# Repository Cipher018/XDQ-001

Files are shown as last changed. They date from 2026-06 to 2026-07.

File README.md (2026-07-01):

# XDQ-001

## Introduction

## What is XDQ-001?

The **XDQ-001**, or **Experimental Drone Quadcopter Model 001**, is a flight platform with an original design. Its experimental objective is to achieve a FPV quadcopter capable of both acrobatic flight and cinematic filming. Furthermore, the XDQ-001 platform serves as a cutting-edge testbed for implementing highly optimized low-level control and autonomous navigation algorithms.

## Whats New?

The **XDQ-001** represents a massive generational leap over its predecessor (XDF-001), integrating the following hardware and firmware innovations (Version V001):

1. **Hybrid Cooperative Interrupt-Based Architecture (No RTOS):**
   - **1000Hz Critical Loop:** Hardware Timer ISR dedicated exclusively to attitude (AHRS), PID calculations, and motor control.
   - **50Hz Kinematic Loop:** Background loop for Kalman filtering, waypoint navigation, and geometric estimation.
2. **Dual-Layer Navigation System:**
   - **Layer 1 (Attitude):** Optimized Mahony AHRS filter running at 1000Hz.
   - **Layer 2 (Kinematics):** Three-Dimensional Error State Kalman Filter (3D ESKF) at 50Hz, fusing accelerometer, GPS, and barometer (BMP280) measurements.
3. **CADI_A Adaptive Navigation System:**
   - Advanced algorithms for L1 navigation (adaptive waypoints) and Orbit (loiter).
   - **Stochastic Wind Estimator (Pitot-less):** Calculates and compensates for crosswind in real-time without requiring a pitot tube, based on geometric discrepancy during turns.
4. **Advanced Flight Control (FlightPID):** Isolated bandwidth PIDs (LPF_PT1 filters on P and D terms).
5. **Dynamic Safety Guards:**
   - *Dynamic Stall Guard:* Dynamic stall prevention based on bank angle.
   - *G-Limiter:* Pilot control limitation when the safe structural G-load (2.0G - 3.5G) is exceeded.
   - *Failsafe RTL:* Safe automatic Return-To-Launch on link loss.
6. **Dedicated Hardware:** MCU STM32F4 (with FPU), dedicated ICM-42688 IMU, MMC5983MA external magnetometer, and SX1280 long-range modem.
7. **Secure Communications & Telemetry:** Frequency Hopping Spread Spectrum (FHSS), logical dual-pipe, and strong cross-block encryption (XXTEA) with integrated CRC16.
8. **Uninterrupted Blackbox Logging:** Lock-free Ping-Pong buffers linked via DMA to the W25Q32JVSS Flash memory.

## Objectives

The primary objective is to develop an exceptional FPV quadcopter capable of both extreme acrobatic flight and smooth cinematic tracking.

The secondary objectives are:
- Provide an ultra-fast, predictable, non-RTOS software framework.
- Consolidate the capabilities of the CADI autonomous ecosystem (Waypoints, Orbits, auto RTL).
- Implement and refine stochastic estimation systems (ESKF and Wind Estimator).
- Establish an impenetrable telemetry system (robust encryption and FHSS).

## Architecture

As previously mentioned, the project is based on the STM32F4 architecture utilizing a hybrid cooperative interrupt-based system. You can consult the documentation section for details regarding the PCB, algorithms, or flowcharts.

## Hardware

The XDQ-001 uses a custom Flight Control Board (FCB) built around the **STM32F4** microcontroller. Key sensors and components:

- **IMU (Gyro/Accel):** ICM‑42688‑P
- **Magnetometer:** MMC5983MA
- **Barometer:** BMP280
- **Radio Link:** SX‑1280 (FHSS Support)
- **Storage:** W25Q32JVSS Flash Memory
- **Camera:** Caddx Baby Ratel 2 (optional)

A full Bill of Materials (BOM) is still being defined.

## Software

- Development is currently performed using the **Arduino IDE** (with the STM32 core) but migration to a more advanced toolchain is planned.
- No ground control station (GCS) software exists yet; a future GCS will communicate via the SX‑1280 radio.

## Compilation & Installation

The firmware follows the standard Arduino IDE project layout:

1. Open the `Firmware/` folder and load `XDQ-001F_V001.ino`.
2. Select the appropriate **STM32F4** board definition.
3. Ensure FPU support is enabled if required.
4. Verify / compile the sketch (`Ctrl+R`) and upload using a compatible programmer (e.g., ST-Link V2) or USB DFU bootloader.

## Usage

1. Power the FCB and connect the radio module.
2. Power the drone and perform a basic motor test (ensure propellers are removed).
3. When the GCS becomes available, pair it with the SX‑1280 radio and start telemetry.

## Configuration

At present the firmware has no runtime‑configurable parameters. Future releases will expose PID and filter tuning via the GCS.

## Contributing

Contributions are welcome under an **MIT license**. Please:

- Fork the repository and create a feature branch.
- Follow the existing code style (Arduino‑C++ with descriptive comments).
- Ensure any additions maintain the non-blocking philosophy of the 1000Hz critical loop.
- Open a Pull Request with a clear description of changes.

## License

This project is licensed under the **MIT License**. See the `LICENSE` file for details.

## Documentation

It is highly recommended to review the comprehensive documentation to understand the mathematical and algorithmic details:

- 📄 **[Firmware Reference Manual (Markdown)](Documentation/firmware_reference.md)**
- 📕 **[Firmware Reference Manual (PDF)](Documentation/firmware_reference.pdf)**
- 📐 [Architecture Diagram](Documentation/architecture.md) (Pending migration)
- 🔌 [Pinout & Hardware](Documentation/pinout.md) (Pending migration)
- 📡 [Protocols](Documentation/protocol.md) (Pending migration)

## Project Structure

The repository is organized as follows:

- **Firmware/** – Arduino sketch source files (`*.ino`, drivers, control algorithms, telemetry).
- **Documentation/** – Design documents, architecture diagrams, pin‑out tables, protocol specifications, and other reference material.
- **CAD/** – 3D models and mechanical drawings for printable parts.
- **PCB/** – PCB design files, gerbers, and component placement.
- **References/** – Datasheets, application notes, and external resources used during development.
- **README.md** – This high‑level overview.
- **LICENSE** – MIT license file.

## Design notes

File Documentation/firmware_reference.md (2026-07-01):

# Firmware Reference Manual - XDQ-001
**Document Version:** 1.0  
**Firmware Version:** V001  
**Platform:** STM32F4 (with FPU)  

---

## Table of Contents
1. [System Architecture](#1-system-architecture)
2. [Dual-Layer Navigation System](#2-dual-layer-navigation-system)
3. [Flight Control & Safety](#3-flight-control--safety)
4. [Adaptive Navigation & Wind Estimation](#4-adaptive-navigation--wind-estimation)
5. [Secure Communications & Telemetry](#5-secure-communications--telemetry)
6. [Blackbox Logging](#6-blackbox-logging)

---

## 1. System Architecture

The XDQ-001 firmware implements a hybrid cooperative interrupt-based architecture (without RTOS) designed to optimize CPU cycles and guarantee strict timings in critical loops.

*   **Critical Attitude Loop (1000Hz):** Executed via a Hardware Timer Interrupt (`Timer_ISR`). This loop handles IMU reading, the AHRS filter, PID calculations, and PWM mixer updates for the motors.
*   **Kinematic and Cooperative Loop (50Hz):** Executed in the main block (`loop`). It handles less time-critical tasks such as reading the GPS, Magnetometer, and Barometer, executing the Kalman Filter, and waypoint navigation.

---

## 2. Dual-Layer Navigation System

One of the main technological innovations of the XDQ-001 is its dual approach to estimating attitude and kinematics.

### 2.1. Layer 1: Mahony AHRS Filter (Attitude)
For high-frequency orientation estimation, the firmware utilizes an optimized **Mahony AHRS** filter, processed in the 1000Hz loop.
*   Integrates raw high-speed readings from the ICM-42688 (Gyroscope and Accelerometer).
*   Maintains short-term stability and calculates quaternions that are converted to Euler angles (Roll, Pitch, Yaw), which are essential for acrobatic flight PIDs.

### 2.2. Layer 2: 3D Error State Kalman Filter (Kinematics)
For autonomous navigation, an Error State Kalman Filter (ESKF) processed at 50Hz fuses data from multiple sensors:
*   **System Model:** Maintains the state vector for 3D position and 3D velocity (N/E/D Position, N/E/D Velocity).
*   **Prediction:** Integrates accelerations transformed to the Earth's geographic frame using the AHRS quaternions.
*   **Update:** Uses latitude, longitude, altitude (fused with Barometer), and velocities provided by the GPS.

---

## 3. Flight Control & Safety

Stabilized control is achieved through an isolated controller class (`FlightPID`), complemented by dynamic aerodynamic safeguards.

### 3.1. Isolated Bandwidth PIDs
The PID loops implement PT1 low-pass filters (`LPF_PT1`) on the Proportional and Derivative terms, allowing more aggressive gains while rejecting electrical noise and mechanical vibrations induced by the frame.

### 3.2. Dynamic Safeguards
*   **Dynamic Stall Guard:** Continuously adjusts the stall speed threshold based on the bank angle. If the aircraft's speed drops below the safe threshold, the system autonomously injects negative pitch (nose down) and raises the throttle.
*   **G-Limiter:** Monitors the total G-load measured by the accelerometers and progressively attenuates pilot setpoints when detecting between 2.0 and 3.5 Gs to protect the structural frame.

---

## 4. Adaptive Navigation & Wind Estimation

The firmware introduces advanced autonomous capabilities from the CADI_A ecosystem.

### 4.1. Stochastic Wind Estimator (Pitot-less)
The XDQ-001 calculates the 2D wind vector by comparing the ground velocity vector (from GPS) with the directional attitude vector (nose direction). By applying a low-pass filter and utilizing averages during turns, the drone can determine wind direction and speed without additional hardware.

### 4.2. Guidance Algorithms (L1 & Orbit)
*   **Adaptive L1 Navigation:** Uses a lateral acceleration (L1) algorithm to smoothly generate roll corrections towards the next waypoint, integrating the crosswind compensation calculated by the wind estimator.
*   **TECS Control (Energy):** Employs a simplified variant of the Total Energy Control System (TECS), managing pitch (potential energy) and throttle (kinetic energy) simultaneously.
*   **Orbit:** Maintains a circular turn radius around a defined point by continuously controlling the radial error.

---

## 5. Secure Communications & Telemetry

The drone communicates using an SX1280 modem.
*   **Dual-Pipe:** Logically separates control/command packets (`0xAA`) and waypoint configuration packets (`0xAC`).
*   **Spread Spectrum (FHSS):** Automatic high-speed frequency hopping across 8 channels to evade interference.
*   **Cryptography:** All telemetry and commands use strong **XXTEA** cross-block encryption coupled with a CRC-16 checksum for authenticity and integrity.

---

## 6. Blackbox Logging

*   **Ping-Pong DMA Access:** Uses lock-free double buffers to write 32-byte logs to the W25Q32JVSS Flash memory. This ensures that data capture (attitude, vibration, motor states) does not halt the 1000Hz loop under any circumstances.

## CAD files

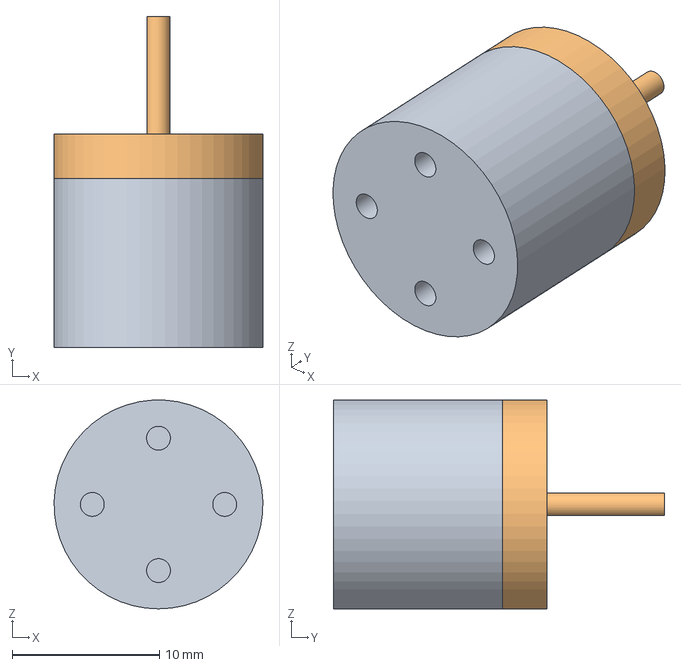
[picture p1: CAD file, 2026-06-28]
CAD/Motor.step
14.2 x 22.5 x 14.2 mm

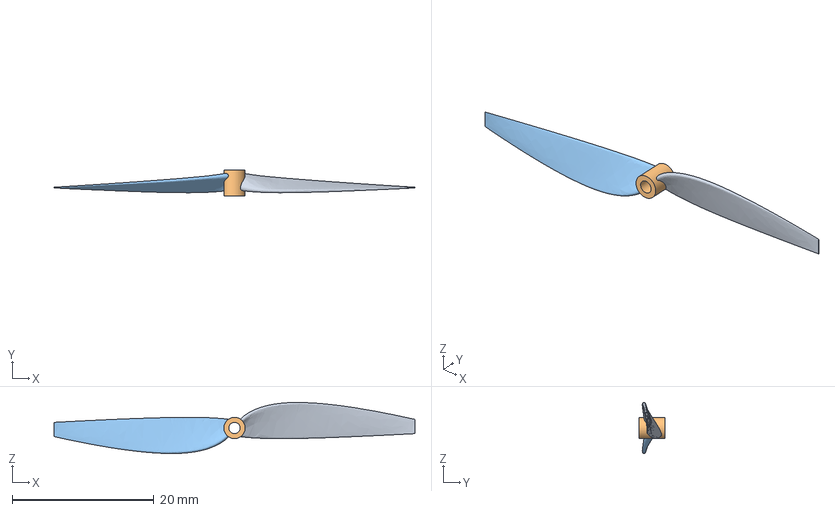
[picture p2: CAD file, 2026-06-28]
CAD/Helice.step
50.9 x 3.70 x 7.20 mm

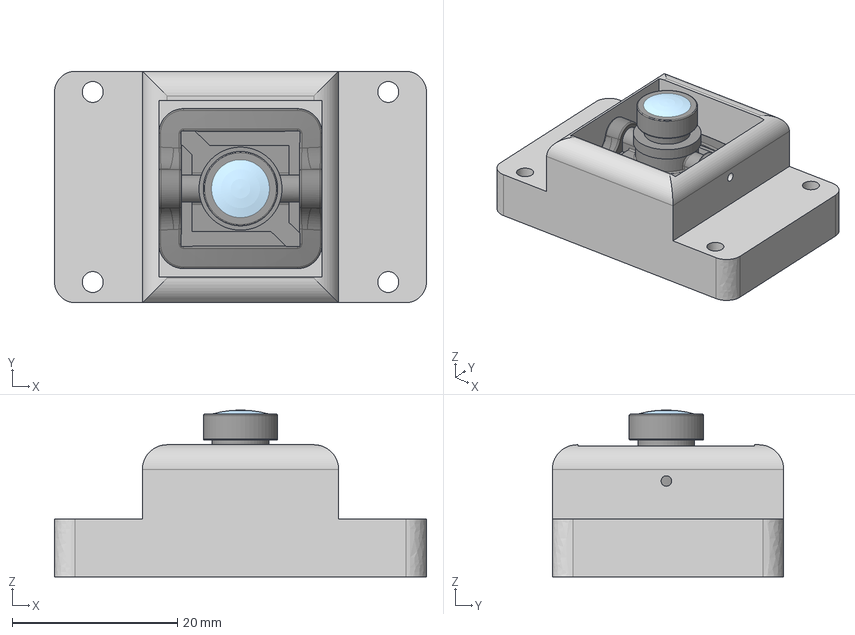
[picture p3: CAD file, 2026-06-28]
CAD/Montura + Camara.step
45.0 x 28.0 x 20.2 mm
CADDX BABY RATEL 2 PROTECTOR
CADDX BABY RATEL 2 CAMERA

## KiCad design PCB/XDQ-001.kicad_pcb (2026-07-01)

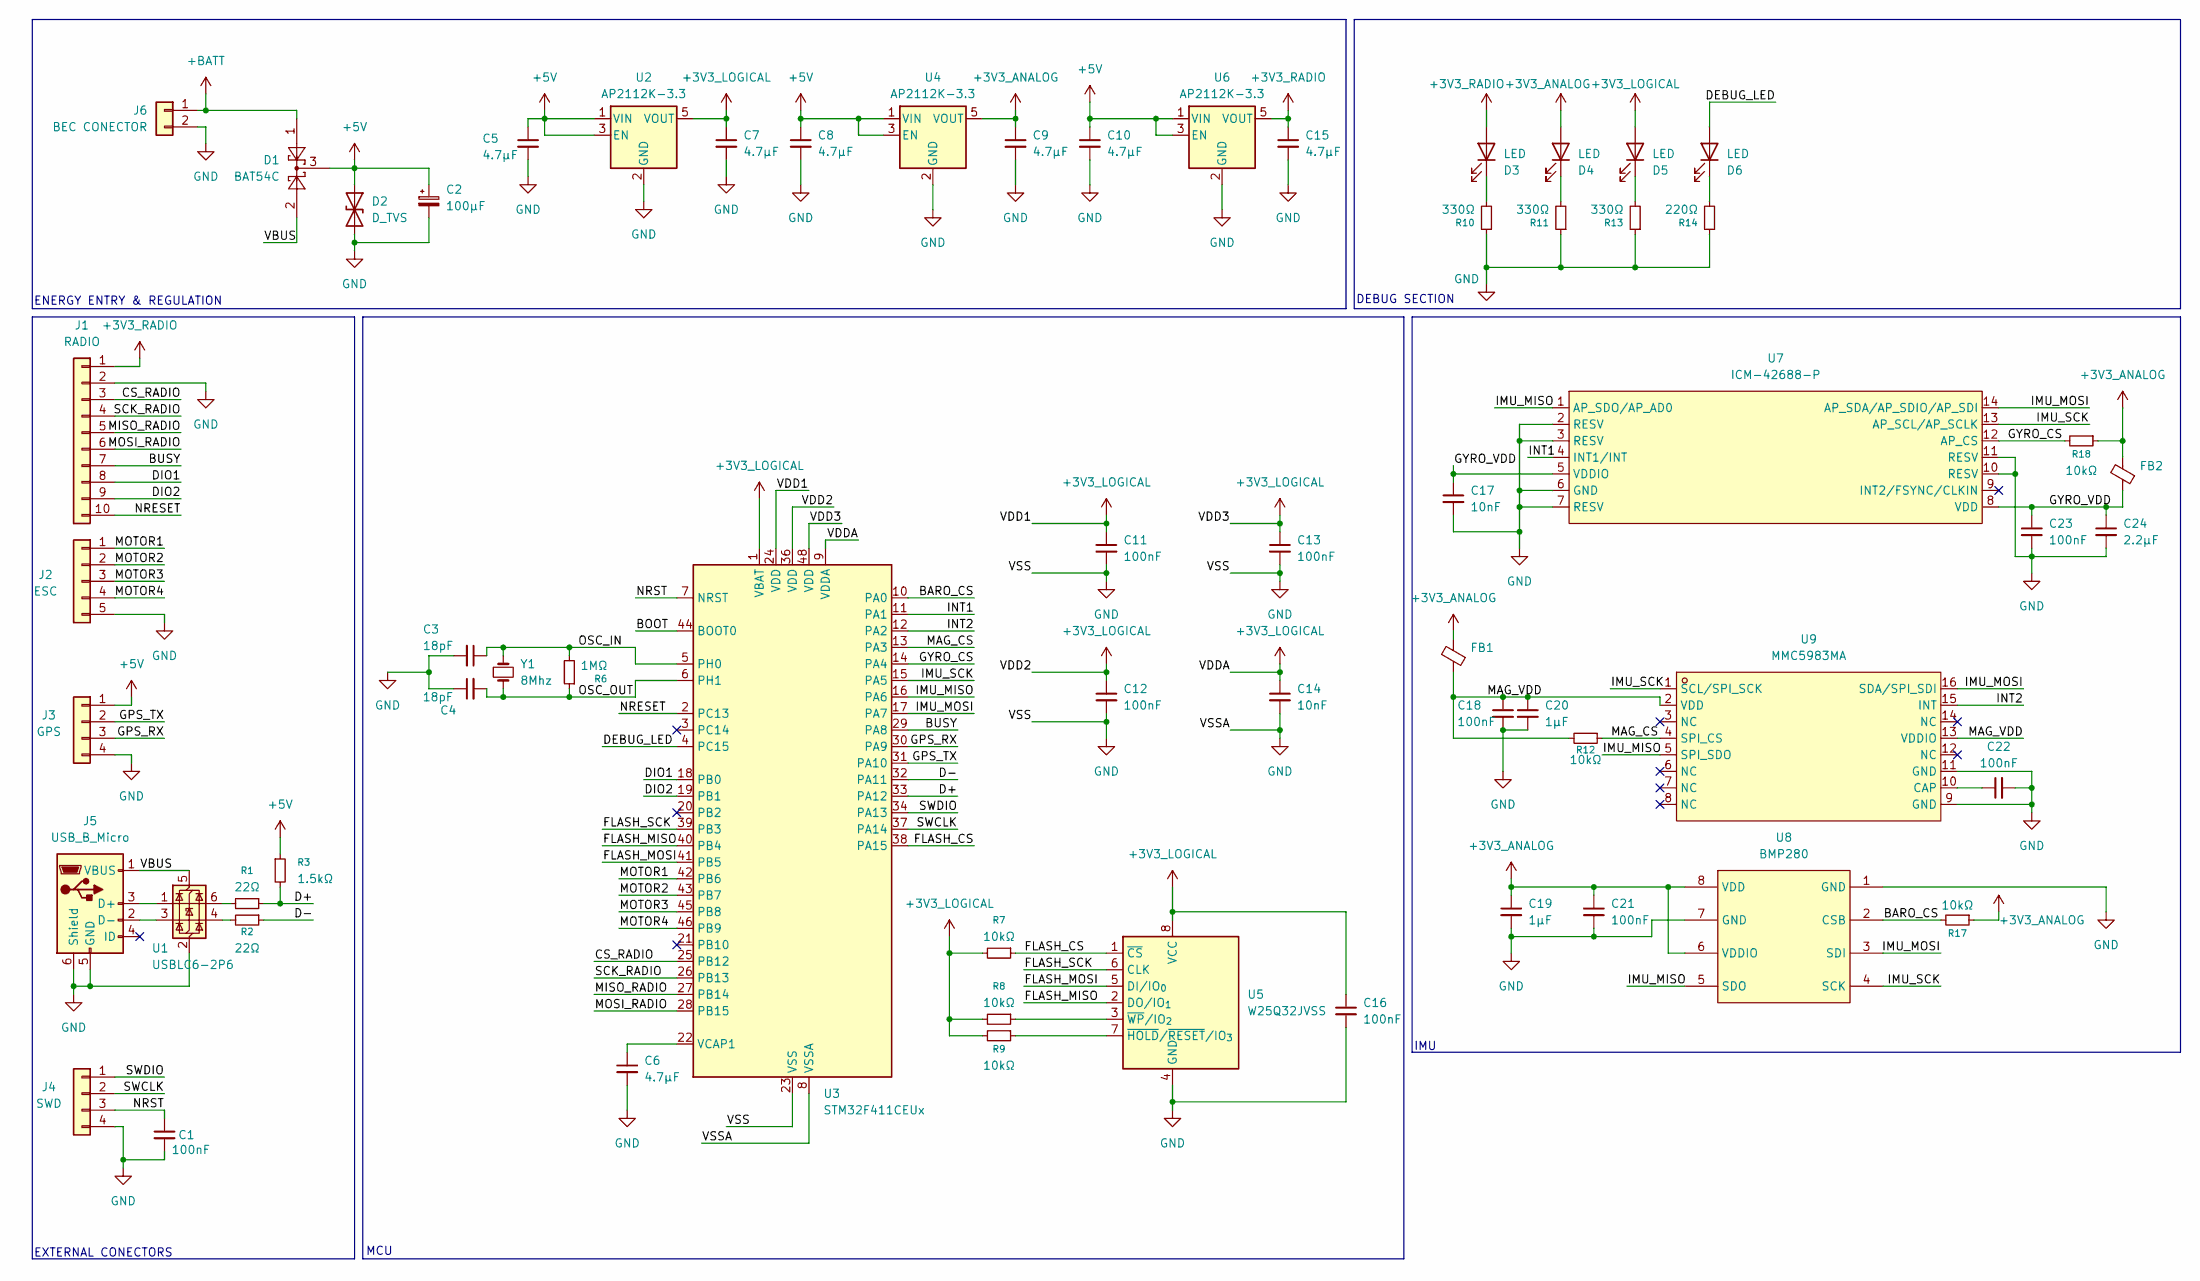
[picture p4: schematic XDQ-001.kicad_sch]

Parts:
C1, C11, C12, C13, C16, C18, C21, C22, C23: 100nF; C_0402_1005Metric_Pad0.74x0.62mm_HandSolder
C2: 100µF; CP_Elec_5x5.3
C3, C4: 18pF; C_0402_1005Metric_Pad0.74x0.62mm_HandSolder
C5, C6, C7, C8, C9, C10, C15: 4.7µF; C_0603_1608Metric_Pad1.08x0.95mm_HandSolder
C14, C17: 10nF; C_0402_1005Metric_Pad0.74x0.62mm_HandSolder
C19, C20: 1µF; C_0603_1608Metric_Pad1.08x0.95mm_HandSolder
C24: 2.2µF; C_0402_1005Metric_Pad0.74x0.62mm_HandSolder
D1: BAT54C; SOT-23
D2: D_TVS; D_SMB
D3, D4, D5, D6: LED; LED_0603_1608Metric_Pad1.05x0.95mm_HandSolder
FB1, FB2: FerriteBead_Small; L_0402_1005Metric
J1: RADIO; SolderWirePad_1x10_SMD_1.5x3mm
J2: ESC; SolderWirePad_1x05_SMD_1.5x3mm
J3: GPS; JST_PH_B4B-PH-K_1x04_P2.00mm_Vertical
J4: SWD; JST_PH_B4B-PH-K_1x04_P2.00mm_Vertical
J5: USB_B_Micro; USB_Micro-B_GCT_USB3076-30-A
J6: BEC CONECTOR; JST_PH_B2B-PH-K_1x02_P2.00mm_Vertical
R1, R2: 22Ω; R_0402_1005Metric_Pad0.72x0.64mm_HandSolder
R3: 1.5kΩ; R_0402_1005Metric_Pad0.72x0.64mm_HandSolder
R6: 1MΩ; R_0402_1005Metric_Pad0.72x0.64mm_HandSolder
R7, R8, R9, R12, R17, R18: 10kΩ; R_0402_1005Metric_Pad0.72x0.64mm_HandSolder
R10, R11, R13: 330Ω; R_0402_1005Metric_Pad0.72x0.64mm_HandSolder
R14: 220Ω; R_0402_1005Metric_Pad0.72x0.64mm_HandSolder
U1: USBLC6-2P6; SOT-666
U2, U4, U6: AP2112K-3.3; SOT-23-5
U3: STM32F411CEUx; QFN-48-1EP_7x7mm_P0.5mm_EP5.6x5.6mm
U5: W25Q32JVSS; SOIC-8_5.3x5.3mm_P1.27mm
U7: ICM-42688-P; LGA-14_L3.0-W2.5-P0.50-TL; MPN ICM-42688-P; LCSC Part C1850418
U8: BMP280; LGA-8_L2.5-W2.0-P0.65_AMP6127; MPN BMP280; LCSC Part C83291
U9: MMC5983MA; LGA-16_L3.0-W3.0-P0.50-BL_SQ; MPN MMC5983MA; LCSC Part C404329
Y1: 8Mhz; Crystal_SMD_2012-2Pin_2.0x1.2mm_HandSoldering

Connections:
+3V3_ANALOG: C9.1, C19.1, C21.1, D4.2 (A), FB1.2, FB2.2, R17.1, R18.1, U4.5 (VOUT), U8.6 (VDDIO), U8.8 (VDD)
+3V3_LOGICAL: C7.1, C11.1, C12.1, C13.1, C14.1, C16.1, D5.2 (A), R7.2, R8.2, R9.2, U2.5 (VOUT), U3.1 (VBAT), U3.9 (VDDA), U3.24 (VDD), U3.36 (VDD), U3.48 (VDD), U5.8 (VCC)
+3V3_RADIO: C15.1, D3.2 (A), J1.1, U6.5 (VOUT)
+5V: C2.1, C5.1, C8.1, C10.1, D1.3, D2.1 (A1), J3.1, R3.1, U2.1 (VIN), U2.3 (EN), U4.1 (VIN), U4.3 (EN), U6.1 (VIN), U6.3 (EN)
+BATT: D1.1, J6.1
/BARO_CS: R17.2, U3.10 (PA0), U8.2 (CSB)
/BOOT: U3.44 (BOOT0)
/BUSY: J1.7, U3.29 (PA8)
/CS_RADIO: J1.3, U3.25 (PB12)
/D+: R1.1, R3.2, U3.33 (PA12)
/D-: R2.1, U3.32 (PA11)
/DEBUG_LED: D6.2 (A), U3.4 (PC15)
/DIO1: J1.8, U3.18 (PB0)
/DIO2: J1.9, U3.19 (PB1)
/FLASH_CS: R7.1, U3.38 (PA15), U5.1 (~CS)
/FLASH_MISO: U3.40 (PB4), U5.2 (DO/IO_{1})
/FLASH_MOSI: U3.41 (PB5), U5.5 (DI/IO_{0})
/FLASH_SCK: U3.39 (PB3), U5.6 (CLK)
/GPS_RX: J3.3, U3.30 (PA9)
/GPS_TX: J3.2, U3.31 (PA10)
/GYRO_CS: R18.2, U3.14 (PA4), U7.12 (AP_CS)
/GYRO_VDD: C17.1, C23.1, C24.1, FB2.1, U7.5 (VDDIO), U7.8 (VDD)
/IMU_MISO: U3.16 (PA6), U7.1 (AP_SDO/AP_AD0), U8.5 (SDO), U9.5 (SPI_SDO)
/IMU_MOSI: U3.17 (PA7), U7.14 (AP_SDA/AP_SDIO/AP_SDI), U8.3 (SDI), U9.16 (SDA/SPI_SDI)
/IMU_SCK: U3.15 (PA5), U7.13 (AP_SCL/AP_SCLK), U8.4 (SCK), U9.1 (SCL/SPI_SCK)
/INT1: U3.11 (PA1), U7.4 (INT1/INT)
/INT2: U3.12 (PA2), U9.15 (INT)
/MAG_CS: R12.1, U3.13 (PA3), U9.4 (SPI_CS)
/MAG_VDD: C18.1, C20.1, FB1.1, R12.2, U9.2 (VDD), U9.13 (VDDIO)
/MISO_RADIO: J1.5, U3.27 (PB14)
/MOSI_RADIO: J1.6, U3.28 (PB15)
/MOTOR1: J2.1, U3.42 (PB6)
/MOTOR2: J2.2, U3.43 (PB7)
/MOTOR3: J2.3, U3.45 (PB8)
/MOTOR4: J2.4, U3.46 (PB9)
/NRESET: J1.10, U3.2 (PC13)
/NRST: C1.1, J4.3, U3.7 (NRST)
/OSC_IN: C3.1, R6.2, U3.5 (PH0), Y1.1
/OSC_OUT: C4.2, R6.1, U3.6 (PH1), Y1.2
/SCK_RADIO: J1.4, U3.26 (PB13)
/SWCLK: J4.2, U3.37 (PA14)
/SWDIO: J4.1, U3.34 (PA13)
/VBUS: D1.2, J5.1 (VBUS), U1.5 (VBUS)
GND: C1.2, C2.2, C3.2, C4.1, C5.2, C6.2, C7.2, C8.2, C9.2, C10.2, C11.2, C12.2, C13.2, C14.2, C15.2, C16.2, C17.2, C18.2, C19.2, C20.2, C21.2, C22.2, C23.2, C24.2, D2.2 (A2), J1.2, J2.5, J3.4, J4.4, J5.5 (GND), J5.6 (Shield), J6.2, R10.1, R11.1, R13.1, R14.1, U1.2 (GND), U2.2 (GND), U3.8 (VSSA), U3.23 (VSS), U3.35 (VSS), U3.47 (VSS), U3.49 (VSS), U4.2 (GND), U5.4 (GND), U6.2 (GND), U7.2 (RESV), U7.3 (RESV), U7.6 (GND), U7.7 (RESV), U7.10 (RESV), U7.11 (RESV), U8.1 (GND), U8.7 (GND), U9.9 (GND), U9.11 (GND)
unnamed: D3.1 (K), R10.2
unnamed: D4.1 (K), R11.2
unnamed: D5.1 (K), R13.2
unnamed: D6.1 (K), R14.2
unnamed: J5.3 (D+), U1.1 (I/O1)
unnamed: J5.2 (D-), U1.3 (I/O2)
unnamed: R1.2, U1.6 (I/O1)
unnamed: R2.2, U1.4 (I/O2)
unnamed: C6.1, U3.22 (VCAP1)
unnamed: R9.1, U5.7 (~HOLD/~RESET/IO_{3})
unnamed: R8.1, U5.3 (~WP/IO_{2})
unnamed: C22.1, U9.10 (CAP)

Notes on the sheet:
EXTERNAL CONECTORS
DEBUG SECTION
IMU
MCU
ENERGY ENTRY & REGULATION

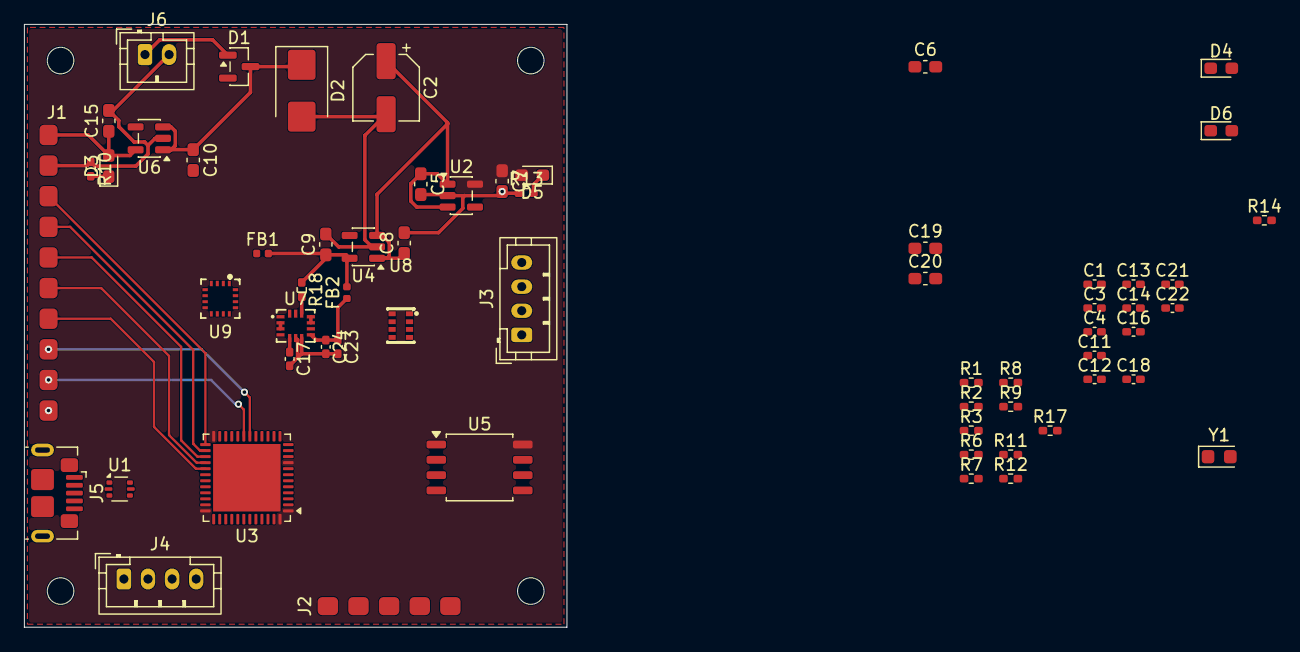
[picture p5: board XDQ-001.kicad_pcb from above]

Board: 4 copper layers, 45.0 x 50.0 mm, 62 parts (0 on the bottom side), 55 nets.

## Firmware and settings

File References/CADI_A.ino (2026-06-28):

#include <Adafruit_PWMServoDriver.h>
#include <ESP32Servo.h>
#include <Preferences.h> // [F5] NVS key storage
#include <RF24.h>
#include <SPI.h>
#include <TinyGPSPlus.h>
#include <Wire.h>
#include <mpu9250.h>
#include <nRF24L01.h>


// ═══════════════════════════════════════════════════════
// TELEMETRY PACKET — OPTIMIZADO
// Tamaño: 4+4+2+2+2+2+2+2+2+2 = 24 bytes (límite nRF24: 32B)
// Conversiones para campos int16:
//   ángulos   × 10  → 0.1° resolución
//   gforce    × 100 → 0.01G resolución
//   velocidad × 100 → 0.01 m/s resolución
// ═══════════════════════════════════════════════════════
struct __attribute__((packed)) TelemetryPacket {
  // Lat/lon como int32 escalado x1e7 para evitar pérdida de precisión de float
  // y problemas de endianness. Rango: ±2147483647 → ±214.7483647°
  int32_t latitude;  // 4B — grados × 1e7  (ej: 4.1234567° → 41234567)
  int32_t longitude; // 4B — grados × 1e7
  int16_t altitude;  // 2B — metros × 10  (−3276m a +3276m, 0.1m res)
  int16_t heading;   // 2B — grados × 10  (0 a 3599 → 0° a 359.9°)
  int16_t pitch;     // 2B — grados × 10  (−900 a +900 → −90° a +90°)
  int16_t roll;      // 2B — grados × 10  (−1800 a +1800)
  int16_t gforce;    // 2B — G × 100      (0 a 800 → 0G a 8G)
  int16_t velocityX; // 2B — m/s × 100    (−5000 a +5000 → ±50 m/s)
  int16_t velocityY; // 2B — m/s × 100
  int16_t velocityZ; // 2B — m/s × 100
  uint8_t seq;       // 1B — Contador incremental para detectar pérdida
  uint8_t _pad[3];   // 3B — padding a 28 bytes (múltiplo de 4 para XXTEA)
}; // Total: 28 bytes ✓

TelemetryPacket telemPkt;

// ═══════════════════════════════════════════════════════
// DUBINS AND VECTOR CLASS
// ═══════════════════════════════════════════════════════
class Vector3D {
public:
  float x, y, z;
  Vector3D(float _x = 0, float _y = 0, float _z = 0) : x(_x), y(_y), z(_z) {}
  Vector3D operator-(const Vector3D &v) const {
    return Vector3D(x - v.x, y - v.y, z - v.z);
  }
  Vector3D operator+(const Vector3D &v) const {
    return Vector3D(x + v.x, y + v.y, z + v.z);
  }
  Vector3D operator*(float s) const { return Vector3D(x * s, y * s, z * s); }
  float magnitude() const { return sqrtf(x * x + y * y + z * z); }
  Vector3D normalize() const {
    float mag = magnitude();
    if (mag < 0.001f)
      return Vector3D(0, 0, 0);
    return Vector3D(x / mag, y / mag, z / mag);
  }
  float dot(const Vector3D &v) const { return x * v.x + y * v.y + z * v.z; }
  Vector3D cross(const Vector3D &v) const {
    return Vector3D(y * v.z - z * v.y, z * v.x - x * v.z, x * v.y - y * v.x);
  }
};

// ── Global Mission State ──
const int MAX_WAYPOINTS = 16;
struct __attribute__((packed)) RouteWaypoint {
  float lat;
  float lon;
  float alt;
  uint8_t mode;      // 1=Waypoint, 2=Orbit
  uint8_t direction; // 0=CCW, 1=CW
  float radius;
};

RouteWaypoint waypointRoute[MAX_WAYPOINTS];
int waypointCount = 0;
int waypointIndex = 0;
bool routeLoop = false;

enum NavigationMode { MODE_MANUAL = 0, MODE_WAYPOINT = 1, MODE_ORBIT = 2 };
NavigationMode currentMode = MODE_MANUAL;

// ═══════════════════════════════════════════════════════
// MAHONY AHRS — Estimación de Actitud con Cuaterniones
// Reemplaza 3 Kalmans 1D independientes. Inmune a gimbal lock.
// Ref: Mahony et al., 2008. Complementary filter on SO(3).
// ═══════════════════════════════════════════════════════
class MahonyAHRS {
public:
  float q0, q1, q2, q3; // Cuaternión [w, x, y, z]
  float integralFBx, integralFBy, integralFBz;
  float twoKp, twoKi;

  MahonyAHRS(float kp = 2.0f, float ki = 0.005f)
      : q0(1.0f), q1(0.0f), q2(0.0f), q3(0.0f), integralFBx(0.0f),
        integralFBy(0.0f), integralFBz(0.0f), twoKp(2.0f * kp),
        twoKi(2.0f * ki) {}

  // Actualización con giroscopio + acelerómetro (en radianes)
  void updateIMU(float gx, float gy, float gz, float ax, float ay, float az,
                 float dt) {
    float recipNorm;
    float halfvx, halfvy, halfvz;
    float halfex, halfey, halfez;

    float norm = sqrtf(ax * ax + ay * ay + az * az);
    if (norm < 0.001f)
      return;
    ax /= norm;
    ay /= norm;
    az /= norm;

    halfvx = q1 * q3 - q0 * q2;
    halfvy = q0 * q1 + q2 * q3;
    halfvz = q0 * q0 - 0.5f + q3 * q3;

    halfex = ay * halfvz - az * halfvy;
    halfey = az * halfvx - ax * halfvz;
    halfez = ax * halfvy - ay * halfvx;

    if (twoKi > 0.0f) {
      integralFBx += twoKi * halfex * dt;
      integralFBy += twoKi * halfey * dt;
      integralFBz += twoKi * halfez * dt;
      gx += integralFBx;
      gy += integralFBy;
      gz += integralFBz;
    }

    gx += twoKp * halfex;
    gy += twoKp * halfey;
    gz += twoKp * halfez;

    gx *= 0.5f * dt;
    gy *= 0.5f * dt;
    gz *= 0.5f * dt;

    float qa = q0, qb = q1, qc = q2;
    q0 += (-qb * gx - qc * gy - q3 * gz);
    q1 += (qa * gx + qc * gz - q3 * gy);
    q2 += (qa * gy - qb * gz + q3 * gx);
    q3 += (qa * gz + qb * gy - qc * gx);

    recipNorm = 1.0f / sqrtf(q0 * q0 + q1 * q1 + q2 * q2 + q3 * q3);
    q0 *= recipNorm;
    q1 *= recipNorm;
    q2 *= recipNorm;
    q3 *= recipNorm;
  }

  // Actualización con magnetómetro adicional
  void updateMag(float gx, float gy, float gz, float ax, float ay, float az,
                 float mx, float my, float mz, float dt) {
    float recipNorm;
    float q0q0 = q0 * q0, q0q1 = q0 * q1, q0q2 = q0 * q2, q0q3 = q0 * q3;
    float q1q1 = q1 * q1, q1q2 = q1 * q2, q1q3 = q1 * q3;
    float q2q2 = q2 * q2, q2q3 = q2 * q3, q3q3 = q3 * q3;
    float hx, hy, bx, bz;
    float halfvx, halfvy, halfvz, halfwx, halfwy, halfwz;
    float halfex, halfey, halfez;

    float norm = sqrtf(ax * ax + ay * ay + az * az);
    if (norm < 0.001f) {
      updateIMU(gx, gy, gz, ax, ay, az, dt);
      return;
    }
    ax /= norm;
    ay /= norm;
    az /= norm;

    norm = sqrtf(mx * mx + my * my + mz * mz);
    if (norm < 0.001f) {
      updateIMU(gx, gy, gz, ax, ay, az, dt);
      return;
    }
    mx /= norm;
    my /= norm;
    mz /= norm;

    hx = 2.0f *
         (mx * (0.5f - q2q2 - q3q3) + my * (q1q2 - q0q3) + mz * (q1q3 + q0q2));
    hy = 2.0f *
         (mx * (q1q2 + q0q3) + my * (0.5f - q1q1 - q3q3) + mz * (q2q3 - q0q1));
    bx = sqrtf(hx * hx + hy * hy);
    bz = 2.0f *
         (mx * (q1q3 - q0q2) + my * (q2q3 + q0q1) + mz * (0.5f - q1q1 - q2q2));

    halfvx = q1q3 - q0q2;
    halfvy = q0q1 + q2q3;
    halfvz = q0q0 - 0.5f + q3q3;
    halfwx = bx * (0.5f - q2q2 - q3q3) + bz * (q1q3 - q0q2);
    halfwy = bx * (q1q2 - q0q3) + bz * (q0q1 + q2q3);
    halfwz = bx * (q0q2 + q1q3) + bz * (0.5f - q1q1 - q2q2);

    halfex = ay * halfvz - az * halfvy + (my * halfwz - mz * halfwy);
    halfey = az * halfvx - ax * halfvz + (mz * halfwx - mx * halfwz);
    halfez = ax * halfvy - ay * halfvx + (mx * halfwy - my * halfwx);

    if (twoKi > 0.0f) {
      integralFBx += twoKi * halfex * dt;
      integralFBy += twoKi * halfey * dt;
      integralFBz += twoKi * halfez * dt;
      gx += integralFBx;
      gy += integralFBy;
      gz += integralFBz;
    }
    gx += twoKp * halfex;
    gy += twoKp * halfey;
    gz += twoKp * halfez;
    gx *= 0.5f * dt;
    gy *= 0.5f * dt;
    gz *= 0.5f * dt;

    float qa = q0, qb = q1, qc = q2;
    q0 += (-qb * gx - qc * gy - q3 * gz);
    q1 += (qa * gx + qc * gz - q3 * gy);
    q2 += (qa * gy - qb * gz + q3 * gx);
    q3 += (qa * gz + qb * gy - qc * gx);

    recipNorm = 1.0f / sqrtf(q0 * q0 + q1 * q1 + q2 * q2 + q3 * q3);
    q0 *= recipNorm;
    q1 *= recipNorm;
    q2 *= recipNorm;
    q3 *= recipNorm;
  }

  float getPitch() const {
    return asinf(2.0f * (q0 * q2 - q3 * q1)) * 57.2958f;
  }
  float getRoll() const {
    return atan2f(2.0f * (q0 * q1 + q2 * q3),
                  q0 * q0 - q1 * q1 - q2 * q2 + q3 * q3) *
           57.2958f;
  }
  float getYaw() const {
    float yaw = atan2f(2.0f * (q0 * q3 + q1 * q2),
                       q0 * q0 + q1 * q1 - q2 * q2 - q3 * q3) *
                57.2958f;
    if (yaw < 0.0f)
      yaw += 360.0f;
    return yaw;
  }
};

MahonyAHRS mahony(2.0f, 0.005f); // kp=2.0, ki=0.005

// ═══════════════════════════════════════════════════════
// KALMAN LINEAL 3D — Fusión GPS + IMU (Cinemática Traslacional)
// Estado: [posN, velN, posE, velE, posD, velD]
// Observación (GPS): posición + velocidad cada ~200ms
// Predicción (IMU): aceleración rotada a Earth-Frame cada 20ms
// ═══════════════════════════════════════════════════════
const float MAX_VEL_GPS = 60.0f;

class KinematicsKF3D {
public:
  // Estado: x[0..1]=posN/velN, x[2..3]=posE/velE, x[4..5]=posD/velD
  float x[6];
  // Covarianza (diagonal — modelo desacoplado por eje)
  float P[6];
  // Ruido de proceso (acelerómetro) y de observación (GPS)
  const float Qa = 0.5f;  // varianza aceleración IMU (m/s^2)^2
  const float Rp = 4.0f;  // varianza posición GPS (m)^2
  const float Rv = 0.25f; // varianza velocidad GPS (m/s)^2

  KinematicsKF3D() {
    for (int i = 0; i < 6; i++) {
      x[i] = 0.0f;
      P[i] = 100.0f;
    }
  }

  // Predicción IMU: aceleración en Earth-Frame (m/s²), ya sin gravedad
  void predict(float aN, float aE, float aD, float dt) {
    float dt2 = dt * dt;
    // Eje Norte
    x[0] += x[1] * dt + 0.5f * aN * dt2;
    x[1] += aN * dt;
    P[0] += P[1] * dt * 2.0f + Qa * dt2 * dt2 * 0.25f;
    P[1] += Qa * dt2;
    // Eje Este
    x[2] += x[3] * dt + 0.5f * aE * dt2;
    x[3] += aE * dt;
    P[2] += P[3] * dt * 2.0f + Qa * dt2 * dt2 * 0.25f;
    P[3] += Qa * dt2;
    // Eje Abajo
    x[4] += x[5] * dt + 0.5f * aD * dt2;
    x[5] += aD * dt;
    P[4] += P[5] * dt * 2.0f + Qa * dt2 * dt2 * 0.25f;
    P[5] += Qa * dt2;
  }

  // Actualización GPS: posición y velocidad observadas
  void updateGPS(float posN, float posE, float posD, float vN, float vE,
                 float vD) {
    // Actualización posición Norte
    _updateScalar(0, posN, Rp);
    // Actualización velocidad Norte
    _updateScalar(1, vN, Rv);
    // Actualización posición Este
    _updateScalar(2, posE, Rp);
    // Actualización velocidad Este
    _updateScalar(3, vE, Rv);
    // Actualización posición Abajo
    _updateScalar(4, posD, Rp);
    // Actualización velocidad Abajo
    _updateScalar(5, vD, Rv);
  }

  float velN() const { return x[1]; }
  float velE() const { return x[3]; }
  float velD() const { return x[5]; }
  float posN() const { return x[0]; }
  float posE() const { return x[2]; }
  float posD() const { return x[4]; }

private:
  void _updateScalar(int idx, float z, float R) {
    float K = P[idx] / (P[idx] + R);
    x[idx] += K * (z - x[idx]);
    P[idx] *= (1.0f - K);
  }
};

KinematicsKF3D kf3d;

// ═══════════════════════════════════════════════════════
// HARDWARE DEFINITIONS
// ═══════════════════════════════════════════════════════
Servo esc;
#define ESC_PIN 14

int servo1Pos = 90, servo2Pos = 90, servo3Pos = 90, servo4Pos = 90;
int servo5Pos = 90, servo6Pos = 90, servo7Pos = 90, servo8Pos = 90;

TinyGPSPlus gps;
bfs::Mpu9250 mpu;

#define GPS_SERIAL Serial2
#define GPS_RX 17
#define GPS_TX 16

#define CE_PIN 5
#define CSN_PIN 4
RF24 radio(CE_PIN, CSN_PIN);
const byte pipeRX[6] = "CMD01";
const byte pipeTX[6] = "TEL01";

// ═══════════════════════════════════════════════════════
// FHSS AND CHANNELS (Salto de frecuencia por software)
// ═══════════════════════════════════════════════════════
const uint8_t fhssChannels[8] = {10, 25, 40, 55, 70, 85, 100, 115};
uint8_t currentChannelIdx = 0;
unsigned long lastPacketReceivedMs = 0;

// ═══════════════════════════════════════════════════════
// SECURITY (XXTEA)
// ═══════════════════════════════════════════════════════
uint32_t sharedKey[4] = {0x58444630, 0x30314B45, 0x595F3230,
                         0x32362121}; // "XDF001KEY_2026!!" en hex
#define XXTEA_DELTA 0x9e3779b9
#define XXTEA_MX                                                               \
  (((z >> 5 ^ y << 2) + (y >> 3 ^ z << 4)) ^                                   \
   ((sum ^ y) + (sharedKey[(p & 3) ^ e] ^ z)))

void btea(uint32_t *v, int n) {
  uint32_t y, z, sum;
  unsigned p, rounds, e;
  if (n > 1) {
    rounds = 6 + 52 / n;
    sum = 0;
    z = v[n - 1];
    do {
      sum += XXTEA_DELTA;
      e = (sum >> 2) & 3;
      for (p = 0; p < n - 1; p++) {
        y = v[p + 1];
        z = v[p] += XXTEA_MX;
      }
      y = v[0];
      z = v[n - 1] += XXTEA_MX;
    } while (--rounds);
  } else if (n < -1) {
    n = -n;
    rounds = 6 + 52 / n;
    sum = rounds * XXTEA_DELTA;
    y = v[0];
    do {
      e = (sum >> 2) & 3;
      for (p = n - 1; p > 0; p--) {
        z = v[p - 1];
        y = v[p] -= XXTEA_MX;
      }
      z = v[n - 1];
      y = v[0] -= XXTEA_MX;
      sum -= XXTEA_DELTA;
    } while (--rounds);
  }
}

// ── Headers Seguros ──
const uint8_t MAGIC_CMD = 0xAA;
const uint8_t MAGIC_TELEM = 0xBB;
const uint8_t MAGIC_WP = 0xAC;

struct __attribute__((packed)) SecureCommand {
  uint8_t magic;
  uint8_t seq;
  uint16_t crc;
  int16_t targetRoll;
  int16_t targetPitch;
  int16_t targetYaw;
  int16_t targetThrottle;
  float homeLat;
  float homeLon;
  int16_t declinationX10;
  uint8_t navMode;  // 0=MANUAL, 1=WAYPOINT, 2=ORBIT
  uint8_t cmdFlags; // Bit 0 = Reset route index
}; // Total: 24 bytes (6 words)

struct __attribute__((packed)) SecureWaypointPacket {
  uint8_t magic; // MAGIC_WP = 0xAC
  uint8_t seq;
  uint16_t crc;
  uint8_t wpIndex; // 0..15
  uint8_t totalWps;
  uint8_t routeLoop; // 0=no, 1=yes
  uint8_t mode;      // NavigationMode (0=MANUAL, 1=WAYPOINT, 2=ORBIT)
  RouteWaypoint wp;  // 18 bytes
  uint8_t _pad[2];   // Pad to 28 bytes (multiple of 4)
}; // Total: 28 bytes (7 words)

struct __attribute__((packed)) SecureTelemetry {
  uint8_t magic;
  uint8_t seq;
  uint16_t crc;
  TelemetryPacket telem;
}; // 32 bytes

SecureCommand secCmd;
SecureWaypointPacket secWpPkt;
SecureTelemetry secTelem;
uint8_t telemSeq = 0;
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
void loop() {
  // Bucle principal vacío, FreeRTOS maneja las tareas en los dos núcleos
  vTaskDelay(pdMS_TO_TICKS(1000));
}

// ═══════════════════════════════════════════════════════
// CORE 1: ESTABILIZACIÓN RÁPIDA (50Hz)
// ═══════════════════════════════════════════════════════
void taskStabilization(void *pvParameters) {
  TickType_t xLastWakeTime = xTaskGetTickCount();
  const TickType_t xFrequency = pdMS_TO_TICKS(20); // Exactamente 20ms (50Hz)

  while (true) {
    float dt = 0.02f;

    if (imuActive) {
      readMPU();

      float rollLocal, pitchLocal;
      float targetRollLocal, targetPitchLocal, targetYawLocal,
          targetThrottleLocal;

      // Lectura y escritura atómica de variables compartidas
      portENTER_CRITICAL(&sharedStateMutex);
      targetRollLocal = targetRoll;
      targetPitchLocal = targetPitch;
      targetYawLocal = targetYaw;
      targetThrottleLocal = targetThrottle;

      // Pasar actitud actual a navegación
      rollLocal = rollDeg;
      pitchLocal = pitchDeg;
      portEXIT_CRITICAL(&sharedStateMutex);

      // 1. Suavizar setpoints de usuario
      float smoothRoll = slewRoll.update(targetRollLocal, dt);
      float smoothPitch = slewPitch.update(targetPitchLocal, dt);

      // 2. Calcular PID
      float rollActuator = pidRoll.compute(smoothRoll, rollLocal, dt);
      float pitchActuator = pidPitch.compute(smoothPitch, pitchLocal, dt);
      float yawActuator = targetYawLocal;

      // Mitigación de Torque Roll: rampa del acelerador para suavizar
      // aceleraciones
      static float currentThrottle = 0.0f;
      float throttleDelta = targetThrottleLocal - currentThrottle;
      float maxThrottleDelta =
          60.0f * dt; // max 60 unidades por segundo de rampa
      if (throttleDelta > maxThrottleDelta)
        currentThrottle += maxThrottleDelta;
      else if (throttleDelta < -maxThrottleDelta)
        currentThrottle -= maxThrottleDelta;
      else
        currentThrottle = targetThrottleLocal;

      // 3. Mezclador a Servos
      servo1Pos = (int)currentThrottle;
      servo2Pos = map(constrain(yawActuator, -40, 40), -40, 40, 50, 130);
      servo3Pos = map(constrain(rollActuator, -45, 45), -45, 45, 45, 135);
      servo4Pos =
          map(constrain(rollActuator, -45, 45), -45, 45, 135, 45); // invertido
      servo5Pos = 90;
      servo6Pos = 90;
      servo7Pos = map(constrain(pitchActuator, -30, 30), -30, 30, 60, 120);
      servo8Pos = map(constrain(pitchActuator, -30, 30), -30, 30, 60, 120);

      // 4. Aplicar al hardware
      esc.write(constrain(servo1Pos, 0, 180));
      setServoAngle(SERVO_CH_YAW, servo2Pos);
      setServoAngle(SERVO_CH_ROLL_L, servo3Pos);
      setServoAngle(SERVO_CH_ROLL_R, servo4Pos);
      setServoAngle(SERVO_CH_FLAP_L, servo5Pos);
      setServoAngle(SERVO_CH_FLAP_R, servo6Pos);
      setServoAngle(SERVO_CH_PITCH_L, servo7Pos);
      setServoAngle(SERVO_CH_PITCH_R, servo8Pos);
    }

    vTaskDelayUntil(&xLastWakeTime, xFrequency);
  }
}

// ═══════════════════════════════════════════════════════
// CORE 0: NAVEGACIÓN Y COMUNICACIONES (10Hz)
// ═══════════════════════════════════════════════════════
static char setKeyLineBuf[32];
static uint8_t setKeyLineIdx = 0;

void handleSetKeyCommand(const char *line) {
  if (strncmp(line, "SET_KEY:", 8) != 0)
    return;
  const char *keyStr = line + 8;
  size_t keyLen = strlen(keyStr);
  uint8_t keyBytes[16] = {0};
  size_t copyLen = keyLen < 16 ? keyLen : 16;
  memcpy(keyBytes, keyStr, copyLen);

  Preferences prefs;
  prefs.begin("pairing", false);
  prefs.putBytes("shared_key", keyBytes, 16);
  prefs.end();

  memcpy(sharedKey, keyBytes, 16);
  Serial.println("[SEC] New key stored in NVS. Restarting...");
  delay(200);
  ESP.restart();
}

void parseSetKeySerial() {
  while (Serial.available()) {
    char ch = (char)Serial.peek();
    if ((uint8_t)ch == MAGIC_CMD || (uint8_t)ch == MAGIC_TELEM ||
        (uint8_t)ch == MAGIC_WP)
      break;
    Serial.read();
    if (ch == '\n' || ch == '\r') {
      if (setKeyLineIdx > 0) {
        setKeyLineBuf[setKeyLineIdx] = '\0';
        handleSetKeyCommand(setKeyLineBuf);
        setKeyLineIdx = 0;
      }
    } else if (setKeyLineIdx < 30) {
      setKeyLineBuf[setKeyLineIdx++] = ch;
    }
  }
}

void taskNavigationComms(void *pvParameters) {
  TickType_t xLastWakeTime = xTaskGetTickCount();
  const TickType_t xFrequency = pdMS_TO_TICKS(100); // 10Hz (100ms)

  while (true) {
    parseSetKeySerial();
    readGPS();

    // ── 1. Salto de frecuencia FHSS por software ──
    handleFhssHopping();

    // ── 2. Recepción de Radio ──
    if (radio.available()) {
      uint8_t len = radio.getDynamicPayloadSize();
      if (len == sizeof(SecureCommand)) {
        radio.read(&secCmd, sizeof(SecureCommand));
        btea((uint32_t *)&secCmd, -6); // Descifrar

        uint16_t crc = calculateRadioCRC16((uint8_t *)&secCmd.targetRoll, 20);
        if (secCmd.magic == MAGIC_CMD && secCmd.crc == crc) {
          static uint8_t lastSeq = 255;
          uint8_t seqDelta = (uint8_t)(secCmd.seq - lastSeq);
          if (seqDelta > 0 && seqDelta <= 128) {
            lastSeq = secCmd.seq;
            lastRFTime = millis();
            lastPacketReceivedMs = millis();

            // Modo de navegación solicitado por GCS
            currentMode = (NavigationMode)secCmd.navMode;

            // Resetear ruta si se indica flag
            if (secCmd.cmdFlags & 0x01) {
              waypointIndex = 0;
            }

            if (currentMode == MODE_MANUAL) {
              // Modo directo (Joystick manual override)
              portENTER_CRITICAL(&sharedStateMutex);
              targetRoll = secCmd.targetRoll;
              targetPitch = secCmd.targetPitch;
              targetYaw = secCmd.targetYaw;
              targetThrottle = secCmd.targetThrottle;
              portEXIT_CRITICAL(&sharedStateMutex);
            }

            magneticDeclinationDeg = secCmd.declinationX10 / 10.0f;
            if (secCmd.homeLat != 0.0f && secCmd.homeLon != 0.0f) {
              homeLat = secCmd.homeLat;
              homeLon = secCmd.homeLon;
            }

            pushTelemetryAck();
          }
        }
      } else if (len == sizeof(SecureWaypointPacket)) {
        radio.read(&secWpPkt, sizeof(SecureWaypointPacket));
        btea((uint32_t *)&secWpPkt, -7); // Descifrar 7 palabras (28 bytes)

        uint16_t crc = calculateRadioCRC16((uint8_t *)&secWpPkt.wpIndex, 24);
        if (secWpPkt.magic == MAGIC_WP && secWpPkt.crc == crc) {
          lastPacketReceivedMs = millis();
          lastRFTime = millis();

          uint8_t idx = secWpPkt.wpIndex;
          if (idx < MAX_WAYPOINTS) {
            waypointRoute[idx] = secWpPkt.wp;
            waypointCount = secWpPkt.totalWps;
            routeLoop = (secWpPkt.routeLoop == 1);
            currentMode = (NavigationMode)secWpPkt.mode;

            if (idx == 0) {
              waypointIndex = 0;
            }
          }
          pushTelemetryAck();
        }
      } else {
        uint8_t dummy[32];
        radio.read(&dummy, len);
      }
    }

    // ── 3. FAILSAFE / AUTOPILOT CONTROL ──
    bool linkLost = (millis() - lastRFTime > 1000);

    if (linkLost) {
      // Pérdida de señal: Invocar RTL autónomo
      currentMode = MODE_WAYPOINT;

      // Si home está establecido, crear waypoint temporal hacia home
      if (homeLat != 0.0f && homeLon != 0.0f) {
        waypointRoute[0].lat = homeLat;
        waypointRoute[0].lon = homeLon;
        waypointRoute[0].alt = 40.0f; // 40m altitud segura RTL
        waypointRoute[0].mode = 1;    // Waypoint
        waypointCount = 1;
        waypointIndex = 0;
        routeLoop = false;
      } else {
        // Fallback: Senda de planeo nivelada si no hay GPS/Home
        portENTER_CRITICAL(&sharedStateMutex);
        targetRoll = 0;
        targetPitch = 3.0f;
        targetThrottle = 0;
        targetYaw = 0;
        portEXIT_CRITICAL(&sharedStateMutex);
        goto endLoop;
      }
    }

    // ── 4. CÁLCULO DE NAVEGACIÓN VECTORIAL COMPLETA ONBOARD ──
    if (currentMode == MODE_WAYPOINT || currentMode == MODE_ORBIT) {
      estimateWind();
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

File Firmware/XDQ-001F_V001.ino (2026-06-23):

/**
 * ═══════════════════════════════════════════════════════════════════════════
 * PLATAFORMA XDQ-001 — FLIGHT CONTROLLER FIRMWARE (V001)
 * ═══════════════════════════════════════════════════════════════════════════
 * Arquitectura: Híbrida Cooperativa Basada en Interrupciones (sin RTOS)
 * MCU: STM32F4 (con FPU habilitada)
 * Frecuencia Lazo Crítico: 1000Hz (Timer Interrupt, 1ms estricto)
 * Frecuencia Lazo Cinemático: 50Hz (Cooperative Background)
 * ═══════════════════════════════════════════════════════════════════════════
 */

#include <Arduino.h>
#include <SPI.h>
#include <Wire.h>

// ── DEFINICIÓN DE PINES (Asignación física de la placa XDQ-001) ──

// Bus SPI 3: Memoria Flash W25Q32JVSS
#define PIN_FLASH_SCK PB3
#define PIN_FLASH_MISO PB4
#define PIN_FLASH_MOSI PB5
#define PIN_FLASH_CS PA15

// Bus SPI 1: Sensores IMU, Magnetómetro, Barómetro
#define PIN_SPI1_SCK PA5
#define PIN_SPI1_MISO PA6
#define PIN_SPI1_MOSI PA7
#define PIN_ICM_CS PA4  // CS Giroscopio / Acelerómetro (ICM-42688)
#define PIN_MAG_CS PA3  // CS Magnetómetro (MMC5983MA)
#define PIN_BARO_CS PA0 // CS Barómetro (BMP280)
#define PIN_ICM_INT PA1 // Interrupción IMU
#define PIN_MAG_INT PA2 // Interrupción Magnetómetro

// Motores (ESC 4-in-1 - Salidas PWM)
#define PIN_MOTOR_1 PB6
#define PIN_MOTOR_2 PB7
#define PIN_MOTOR_3 PB8
#define PIN_MOTOR_4 PB9

// Bus SPI 2: Radio SX1280
#define PIN_RADIO_CS PB12
#define PIN_RADIO_SCK PB13
#define PIN_RADIO_MISO PB14
#define PIN_RADIO_MOSI PB15
#define PIN_RADIO_BUSY PA8
#define PIN_RADIO_RST PC13
#define PIN_RADIO_DIO1 PB0
#define PIN_RADIO_DIO2 PB1

// GPS NEO-6M (USART1)
#define PIN_GPS_RX PA10 // Conecta a TX del GPS (STM32 RX)
#define PIN_GPS_TX PA9  // Conecta a RX del GPS (STM32 TX)

// Debug LED
#define PIN_DEBUG_LED PC15

// ── INSTANCIAS DE BUSES SPI Y UART ──
SPIClass SPI_Sensors(PIN_SPI1_MOSI, PIN_SPI1_MISO, PIN_SPI1_SCK);
SPIClass SPI_Radio(PIN_RADIO_MOSI, PIN_RADIO_MISO, PIN_RADIO_SCK);
SPIClass SPI_Flash(PIN_FLASH_MOSI, PIN_FLASH_MISO, PIN_FLASH_SCK);

#define GPS_Serial Serial1

// ── HARDWARE TIMER (1000Hz Scheduler) ──
HardwareTimer *Timer_1kHz = nullptr;

// ── ESTRUCTURAS DE DATOS Y TELEMETRÍA ──

struct __attribute__((packed)) TelemetryData {
  int32_t latitude;  // grados × 1e7
  int32_t longitude; // grados × 1e7
  int16_t altitude;  // metros × 10
  int16_t heading;   // grados × 10 (0 a 3599)
  int16_t pitch;     // grados × 10
  int16_t roll;      // grados × 10
  int16_t gforce;    // G × 100
  int16_t velocityN; // m/s × 100
  int16_t velocityE; // m/s × 100
  int16_t velocityD; // m/s × 100
  uint8_t seq;       // Contador incremental
  uint8_t _pad[3];   // Padding
}; // Total: 28 bytes

struct __attribute__((packed)) SecureTelemetry {
  uint8_t magic; // 0xBB
  uint8_t seq;
  uint16_t crc;
  TelemetryData data;
}; // Total: 32 bytes (8 words)

struct __attribute__((packed)) SecureCommand {
  uint8_t magic; // 0xAA
  uint8_t seq;
  uint16_t crc;
  int16_t targetRoll;     // grados x 10
  int16_t targetPitch;    // grados x 10
  int16_t targetYaw;      // grados x 10
  int16_t targetThrottle; // 0 a 1000
  float homeLat;
  float homeLon;
  int16_t declinationX10;
  uint8_t navMode;  // 0=Manual, 1=Waypoint, 2=Orbit
  uint8_t cmdFlags; // Bit 0 = Reset route index
}; // Total: 24 bytes (6 words)

struct __attribute__((packed)) RouteWaypoint {
  float lat;
  float lon;
  float alt;
  uint8_t mode;      // 1=Waypoint, 2=Orbit
  uint8_t direction; // 0=CCW, 1=CW
  float radius;
}; // Total: 18 bytes

struct __attribute__((packed)) SecureWaypointPacket {
  uint8_t magic; // 0xAC
  uint8_t seq;
  uint16_t crc;
  uint8_t wpIndex; // 0..15
  uint8_t totalWps;
  uint8_t routeLoop; // 0=no, 1=yes
  uint8_t mode;      // NavigationMode (0=MANUAL, 1=WAYPOINT, 2=ORBIT)
  RouteWaypoint wp;
  uint8_t _pad[2]; // Pad a 28 bytes (7 words)
}; // Total: 28 bytes

// Estructura de registro Blackbox (Log de vuelo) - 32 bytes
struct __attribute__((packed)) LogPacket {
  uint32_t timestamp_us;
  int16_t roll_deg_x10;
  int16_t pitch_deg_x10;
  int16_t yaw_deg_x10;
  int16_t gyro_x;
  int16_t gyro_y;
  int16_t gyro_z;
  int16_t accel_x;
  int16_t accel_y;
  int16_t accel_z;
  uint16_t motors[4];
  uint8_t flags;
  uint8_t padding;
};

// Clase Vector3D para Cálculos de Navegación Geométrica
class Vector3D {
public:
  float x, y, z;
  Vector3D(float _x = 0, float _y = 0, float _z = 0) : x(_x), y(_y), z(_z) {}
  Vector3D operator-(const Vector3D &v) const {
    return Vector3D(x - v.x, y - v.y, z - v.z);
  }
  Vector3D operator+(const Vector3D &v) const {
    return Vector3D(x + v.x, y + v.y, z + v.z);
  }
  Vector3D operator*(float s) const { return Vector3D(x * s, y * s, z * s); }
  float magnitude() const { return sqrtf(x * x + y * y + z * z); }
  Vector3D normalize() const {
    float mag = magnitude();
    if (mag < 0.001f)
      return Vector3D(0, 0, 0);
    return Vector3D(x / mag, y / mag, z / mag);
  }
  float dot(const Vector3D &v) const { return x * v.x + y * v.y + z * v.z; }
  Vector3D cross(const Vector3D &v) const {
    return Vector3D(y * v.z - z * v.y, z * v.x - x * v.z, x * v.y - y * v.x);
  }
};

// Configuración de Rutas de Navegación
const int MAX_WAYPOINTS = 16;
RouteWaypoint waypointRoute[MAX_WAYPOINTS];
int waypointCount = 0;
int waypointIndex = 0;
bool routeLoop = false;

enum NavigationMode { MODE_MANUAL = 0, MODE_WAYPOINT = 1, MODE_ORBIT = 2 };
NavigationMode currentMode = MODE_MANUAL;

const float WP_CAPTURE_NEAR = 8.0f; // metros
const float STALL_SPEED = 6.0f;     // m/s
float homeLat = 0.0f;
float homeLon = 0.0f;

// Estimador de Viento sin Pitot (Triángulo Estocástico en Virajes)
float windX = 0.0f; // Viento Este (m/s)
float windY = 0.0f; // Viento Norte (m/s)

// Buffers Ping-Pong Lock-free para Flash W25Q32JVSS
#define FLASH_PAGE_SIZE 256
volatile uint8_t flash_buffer_1[FLASH_PAGE_SIZE];
volatile uint8_t flash_buffer_2[FLASH_PAGE_SIZE];
volatile uint8_t *volatile active_write_buffer = flash_buffer_1;
volatile uint16_t buffer_index = 0;

volatile bool flash_buffer_ready_to_write = false;
volatile uint8_t *volatile dma_write_buffer = nullptr;
volatile uint32_t flash_write_address = 0;

// Variables Globales Compartidas
volatile float latitude = 0.0f;
volatile float longitude = 0.0f;
volatile float altitudeM = 0.0f;
volatile float velN = 0.0f, velE = 0.0f, velD = 0.0f;
volatile float rollDeg = 0.0f, pitchDeg = 0.0f, yawDeg = 0.0f;
volatile float totalGForce = 1.0f;

volatile float setpoint_roll = 0.0f;
volatile float setpoint_pitch = 0.0f;
volatile float setpoint_yaw = 0.0f;
volatile float setpoint_throttle = 0.0f;

float magneticDeclinationDeg = -6.0f;
bool firstGPSFix = true;
float lastLat = 0.0f, lastLon = 0.0f, lastAlt = 0.0f;
uint32_t lastGPSVelTime = 0;
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

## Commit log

2026-06-13 Initial post
    [MP1584.sch.kicad_sch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]
2026-06-13 Deleted temp files
    [MP1584.sch.kicad_sch, freerouting.dsn]
2026-06-13 Creating root files
    [XDQ-001-B_Cu.gbr, XDQ-001-B_Mask.gbr, XDQ-001-B_Paste.gbr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]
2026-06-23 feat: initialize project directory with KiCad design files, firmware, and reference documentation
    [XDQ-001.kicad_pcb, XDQ-001.kicad_sch, temp-freerouting.dsn]
2026-06-28 feat: Created gerbers and CAD files
    [Helice.step, Montura + Camara.step, Motor.step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]
2026-06-29 feat: initialize new KiCad project files and update README
    [XDQ-001.kicad_sch]
2026-07-01 Updated FCB and documentation
    [XDQ-001.kicad_pcb, XDQ-001.kicad_sch]
